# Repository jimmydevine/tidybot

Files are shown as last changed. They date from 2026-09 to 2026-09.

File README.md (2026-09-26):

# TidyBot

A modular cleaning robot for hard floors, heavy dog hair and automatic operation
across two floors. The project is intended to become open source and adaptable to
different homes and component inventories.

| Section | Purpose |
|---|---|
| Middle electronics core | Shared battery, power distribution, central computing and structural frame |
| Bottom working unit | Wheeled vacuum/mop, or airborne duster with passive feet; resident sofa extension fits the vacuum |
| Top unit | Cap/display or a lift assembly carrying the core and attached bottom |

The completed system must clean, exchange tool modules and swap battery
cartridges automatically. Stations keep spare packs charged while the robot works.
Stations use removable bulk water and waste containers; periodic manual servicing
is accepted. Vacuuming comes first, then mopping and higher-area cleaning.

## Current work: whole-system design

**Bottom-frame comparison:** [T was rejected](docs/BOTTOM_CHASSIS.md).
Keeping the separate motor supports while integrating the surrounding frame adds
about **55 g** and obstructs head withdrawal. The [interactive review](design/system/output/bottom_chassis.html)
shows the material and conflicts. No new mass increase is adopted. The whole old
support/caster scope is only 681 g against a 775 g vacuum deficit, so chassis
changes alone cannot meet the limit. Next compare a chassis carrying the motor
brackets directly, plus lighter power-converter and bin/air-path construction.

**Core support comparison:** [S combines equipment supports and the fixed battery
receiver](docs/CORE_SUPPORT.md), with an [interactive cartridge-path view](design/system/output/core_support.html).
The replacement is about 154 g versus the former 210 g local allocation, a
conditional saving of about 56 g. Battery cells, the complete cartridge, sensors,
protection and module locks remain. This alone projects a 5.219 kg vacuum transfer
assembly, still about 719 g above the limit; no saving is booked yet. T above
evaluates the separately budgeted bottom frame and drive/power supports.

**Integrated head frame:** [R combines the end walls, pivot seats, skids and
pitch-stop supports](docs/INTEGRATED_HEAD.md), with [geometry views](design/system/output/integrated_head.svg)
and a [part-by-part mass comparison](design/system/output/integrated_head.md).
The candidate is about 162 g against the existing 170 g frame/compliance scope:
only about 8 g conditional saving. Powered lift remains. The withdrawal check
also corrects carrier-support interference with the wheel envelopes. Larger
shared assemblies still need redesign to close the weight deficit; no new saving
is booked and these are review models, not fabrication files.

**Owner mass budgets:** [4.5 kg maximum for transfer flights and 3.5 kg target
for sustained hovering](docs/MASS_BUDGETS.md), including core, battery and
loaded working module, excluding the lift top. The
[current budget check](design/system/output/mass_budgets.md) identifies the
remaining reductions; an estimate above its budget remains a redesign candidate.

**Sofa attachment direction:** keep [one dock-swapped extension on each floor](docs/SOFA_ATTACHMENT.md).
It replaces the ordinary powered head while sharing the vacuum drivetrain,
bin, filter and blower. Park the extension and reinstall the normal head before
flight. The [layout comparison](design/system/output/sofa_attachment.html)
reserves a 615 mm stowed depth; the owner confirmed approximate sofa approach
and turning space. Receiver placement now clears sampled head motion; complete
automatic head exchange remains to resolve. Including its proposed interface, the ordinary transfer assembly
is 5.275 kg at maximum modeled debris, still **775 g above the 4.5 kg budget**.

**Head coupling detail:** [P carrier and supported exchange](docs/HEAD_COUPLING.md)
adds local FreeCAD/STEP assemblies, a documented contact reference and an
[interactive withdrawal view](design/system/output/head_coupling.html).
The revised interface needs 120 mm withdrawal and 735 mm station handling
depth before margins. Carrier scope is about 68 g against an allocation of
70 g drawn from existing allowances; complete head compliance, latch guides
and service supports remain unfinished. The complete transfer estimate above
is unchanged. This candidate does not release print files or purchases.

**Weight correction:** the [mass audit and revised work direction](docs/MASS_OPTIMIZATION_REVIEW.md)
take priority over extending the K/M mechanisms. Their rising totals combine
heavy separate wheel supports with additional, partly overlapping allowances.
Next compare a simpler integrated chassis and vacuum-head support, reconcile
one mass entry per physical part, and retain cleaning/automation requirements.
The studies below remain comparison candidates; no weight savings are yet booked.

**Q passive-head comparison:** [independent slides with low head pivots](docs/PASSIVE_HEAD.md)
provide the required sampled travel/tilt, but require redesigned cassette end
frames. The [interactive model](design/system/output/passive_head.html) shows
the motion. A separate dock-only mechanism offers only 22–25 g conditional
saving and has unresolved friction/release behavior. Keep the lift allowance;
integrate the guides into the existing head frame before adding hardware.

**N simplification comparison:** [fixed motor supports and a common crossmember](docs/FIXED_DRIVE_COMPARISON.md)
offer a conditional **230 g reduction**, with all other M allowances retained.
The [interactive review](design/system/output/fixed_drive.html) shows the cost:
greater head travel/tilt and an unresolved wet-threshold load split in the mop.
Complete those checks before adopting the candidate or changing the main mass
ledger. Nominal geometry and a complete local mass scope are available for review.

**M floating-head integration:** the [motion and load study](docs/FLOATING_HEAD_DESIGN.md)
adds separate moving-head mass and proposes clearance for working/raised heads.
The [interactive views](design/system/output/floating_heads.html) show the revised
vacuum power shelf, mop tank and shared electronics positions. Sampled height
stays below 180 mm; added mount/lift allowances bring the vacuum/mop planning
cases to **5.32 / 4.95 kg**. Tightened roller/drive envelopes and actual guide/lift
hardware still need detailed fit checks. No new print or purchase is released.

**L spring and ride-height study:** the [updated suspension calculation](docs/SUSPENSION_SPRING_SELECTION.md)
separates moving pod weight from spring-supported load and checks empty/full
containers, tool pressure and caster direction. The
[interactive results](design/system/output/suspension_springs.html) show fixed
settings for each module and a 10.7 mm stock spring candidate. Nominal spring
checks pass, while some tolerance cases fail. Complete spring selection and
floating-head integration before fabrication; K carried-mass estimates remain.

**K connected drivetrain candidate:** the [pod joints and captured stops](docs/POD_JOINTS_AND_STOPS.md)
add a metal tray, bearing blocks and bolted frame connections. The
[interactive review](design/system/output/pod_joints.html) shows the closed stop
slot. Including the detailed pod hardware raises current ground mass planning
to about **5.14 kg vacuum, 4.86 kg mop and 5.42 kg sofa vacuum**. Spring selection,
remaining joint qualification and fabrication details remain open. L supersedes
K's preload-range inference; G/J are preserved for comparison.

**J wheel-pod mechanism candidate:** the [moving cradle and spring design](docs/WHEEL_POD_MECHANISM.md)
adds a catalog motor bracket, an 8 mm pivot with internal retainers, and rocking
spring seats. Review the [interactive mechanism](design/system/output/wheel_pod.html).
The detailed pin load screen passes, but complete joints, stops and spring
selection remain open. The sofa module is already at the preload limit; the
installed mass must be reconciled before selecting springs or claiming savings.

**I height/mounting candidate:** the [revised layout](docs/HEIGHT_AND_CASTER_LAYOUT.md)
uses a C1 lidar and rotated lift-connector reservation to retain the proposed
wheel travel at a sampled 177.35 mm height, or 179.35 mm with a 2 mm reserve.
A documented caster fitting now has space for its full threaded stem; nearby
equipment moves upward while meeting the existing bin/tank volume targets.
Start with the [interactive comparison](design/system/output/height_mounting.html).
Caster retention and detailed suspension joints remain open; G is still the
complete mass baseline.

**H suspension/support study:** [wheel pivots and caster support](docs/FLOOR_SUPPORT_DESIGN.md)
adds mechanism CAD, impact/spring calculations and an
[interactive travel view](design/system/output/floor_support.html). The proposed
downward wheel travel exposes a height conflict: the nominal 179.1 mm pose can
reach about 181.9 mm in the support model. Frame joints and caster fitting remain
open; G's complete mass estimates remain unchanged.

**Revision G frame candidate:** the [dimensioned corner/frame design](docs/FRAME_JOINT_DESIGN.md)
adds a metal load path through the module joints and checks it against the existing
600 N factored requirement. It adds about 14 g to the F estimate and brings
modeled ground height to 179.1 mm. The floor bridge route is cleared, while its
unfinished replacement supports remain fully counted. Start with the
[core frame CAD](design/system/output/frame_joints_core.FCStd) or
[joint drawing](design/system/output/frame_joints.svg).

**Revision F power-partition candidate:** the [new layout and mass comparison](docs/CORE_POWER_PARTITION.md)
moves floor-specific converters out of the shared core. It saves an estimated
246 g on the airborne duster and 103 g on the mop; vacuum/sofa assemblies gain
87 g with the added support/interface allowances. See the
[F viewer](design/system/output/core_partition.html) for the proposed layout.
The C/E viewers below retain the earlier layout and mass for comparison.

The [weight optimization review](docs/MASS_OPTIMIZATION_REVIEW.md) identifies
unfinished mass allowances and redesign priorities across every module. Current
weights are feasibility estimates; they are not the minimum achievable design.

**Revision E airborne supplement:** the preferred elevated duster omits its
drivetrain, suction system and sofa telescope. See the
[interactive airborne comparison](design/system/output/airborne_dusting.html) and
[dusting design](docs/AIRBORNE_DUSTING.md) for its 481 g nominal tool bottom,
rear-boom balance, documented EDF mass/power comparisons, automatic station
handling and complete flight-energy budgets.
The earlier wheeled duster below remains comparison evidence. Vacuum, mop and
under-sofa modules retain their drive.

**2026-09-13, revision C review: design every module before selecting battery cells.** The active
[whole-system design](docs/SYSTEM_DESIGN.md) covers the electronics/sensor core,
vacuum/drive, mop/drive, under-sofa vacuum, duster, whole-assembly lift and automatic
stations. It supersedes the earlier instruction to defer lift sizing and the
battery-first preference. Existing motor/controller, brush/filter and blower
orders remain recorded; this study adds no purchases.

Start with the [interactive layout and budget viewer](design/system/output/system_design.html).
It compares complete assemblies, batteries, payload and assumed guard loss, with
stowed/extended views and individual component inspection. The
[generated report](design/system/output/system_budget.md),
[robot hardware CSV](design/system/output/system_hardware.csv),
[station hardware CSV](design/system/output/station_hardware.csv) and
[FreeCAD/STEP layouts](design/system/README.md) make the design reviewable.
Inputs are in [system_design.json](config/system_design.json).

[Automatic battery exchange](docs/BATTERY_EXCHANGE.md) now uses a cartridge,
station logic power during handling, and two spare packs in four bays per floor.
Five packs serve the two-floor system, with one carried. Capacity and current
capability remain open; extra packs do not establish unlimited cleaning or flight.

[Lift footprint review](docs/LIFT_LAYOUT_REVIEW.md) explains why the earlier
rotor layout became long. The owner considers its 644 × 1444 mm size excessive;
compact lift and duster geometry are now under review. The updated dusting target
is ceiling fans about 7 ft high, 1 ft below the ceiling, with about 2 ft tool reach.
Baseline duster CAD retains the previous horizontal mechanism; the airborne
supplement provides the rear angled-boom reference for fan-edge access. The longer under-sofa telescope remains required.
The review now includes [weight priorities and ducted-fan comparisons](docs/LIFT_LAYOUT_REVIEW.md#weight-reduction-and-ducted-fan-comparison):
compare complete guarded-propeller, hover-duct and compact EDF installations
before selecting a smaller lift layout or revising the mass allowances.

The everyday floor configurations use a **275 × 275 × 180 mm** nominal allocation
and 270 mm main print panels. The [suspension travel envelope](docs/FLOOR_SUPPORT_DESIGN.md)
still needs qualification. G's earlier estimated loaded floor mass is **4.49–5.06 kg**;
the K drivetrain scenario above increases it to about **4.86–5.42 kg**. Earlier
modeled normal power is **58–122 W**. These are engineering estimates, not
measurements. The eight-rotor lift candidate is much larger: approximately
644 × 1444 mm, about 8.2–8.5 kg complete nominal mass and over 2 kW estimated hover
power. Several upper mass cases fail the thrust-margin screen. Battery current
delivery, flight qualification, custom locks/power hardware, telescope mechanics
and detailed fabrication remain open.

The owner updates and unresolved design gates are retained in the
[design document](docs/SYSTEM_DESIGN.md#13-fabrication-verification-and-remaining-work).
Earlier studies below remain evidence and implementation history; the whole-system
record controls current layout, carried mass and battery decisions.

## Earlier component and ground studies

| Earlier record | Contents |
|---|---|
| [Selected-component integration viewer](design/ground/output/vacuum_integration.html) | Rotatable current placement, layer controls, dimensions and service views; not printable geometry |
| [Integration decisions](docs/VACUUM_INTEGRATION.md) | Trailing wheel pods, interchangeable head, rear bin/filter/blower arrangement and unresolved fit |
| [Converter and caster packaging](docs/VACUUM_POWER_PACKAGING.md) | Distributor converter baseline, cooling stack, corrected swivel allowance and docking clearance |
| [Power and remaining hardware](docs/VACUUM_POWER_AND_HARDWARE.md) | Functional diagram, load allocations and consolidated procurement worksheet with open selections |
| [Ground component recommendation](docs/GROUND_COMPONENT_RECOMMENDATION.md) | Proposed geared drive, 72 mm compliant wheels, wet-floor layout and cleaning-component selection; prices and remaining integration work |
| [Drivetrain sourcing](docs/DRIVETRAIN_SOURCING.md) | Exact distributor part numbers and prices; stock versus Marketplace/on-demand fulfillment; conditional motor and controller alternatives |
| [Current vacuum build plan](docs/VACUUM_MODULE_NEXT_PASS.md) | Orders, work during delivery, arrival checks, first assembly and cleaning milestones; retained earlier layout study |
| [Vacuum recommendation review](docs/VACUUM_RECOMMENDATION_REVIEW.md) | Hair-priority brush investigation, cutting versus shedding, washable-filter candidate, sourcing and evidence limits |
| [Cassette and brush comparison plan](docs/VACUUM_CASSETTE_PLAN.md) | Two levels of replacement, first comparison samples, receiver/air/electrical interface, build order and pickup trials |
| [Earlier vacuum component selection](docs/VACUUM_COMPONENT_SELECTION.md) | Superseded consumable choice; retained blower sources, curve discrepancies, airflow and power calculations |
| [Ground module design](docs/GROUND_MODULE_DESIGN.md) | Core, vacuum, cap, automatic joints and next physical milestones |
| [Low-clearance bottom](docs/LOW_CLEARANCE_HEAD.md) | Separate interchangeable bottom; 50 mm clearance, 36-inch depth and front-only access |
| [Owned-parts reuse](docs/OWNED_PARTS_REUSE.md) | Pi 4, A1 LiDAR, 60 mm wheel reference, two 18 RPM encoder motors and CBM blower; missing electronics |
| [Drive motor alternatives](docs/DRIVE_MOTOR_OPTIONS.md) | Faster encoder gearmotors for 90/60 mm wheels; prices, torque limits, mounts and control requirements |
| [Rolling drive rig](design/experiments/drive_rig/README.md) | Optional BDUAV experiment, paused as the robot's development path; fit history and recording tools retained |
| [Rig preparation before controller delivery](design/experiments/drive_rig/PREPARATION.md) | Two ST boards purchased; remaining supplies, fit checks, measurement worksheet and USB-only diagnostics |
| [Vacuum head and consumables](docs/VACUUM_HEAD.md) | Owned roller/brush/filter kit, proposed cassette and remaining fit measurements |
| [Dimensioned head layout](design/ground/output/vacuum_head_layout.html) | Compare both roller lengths; measured envelopes and proposed cassette clearances |
| [Earlier inventory-based placement](design/ground/output/ground_layout.html) | Core, complete vacuum bottom and cap; dimensioned views and service paths |
| [Earlier placement decisions](docs/GROUND_PLACEMENT.md) | Proposed 275 × 275 × 178 mm body, side-access core trays, rear bin, joint zones and station separation |
| [Inventory record](config/owned_parts.json) | Owned variants, quantities where known, missing items and resolved questions |
| [Ground component ledger](config/ground_components.csv) | Per-assembly requirements, candidates and measured mass fields; not an order |
| [Assembly mass record](config/ground_assemblies.csv) | Complete sections with empty/loaded states kept separate |
| [Design proposal](docs/DESIGN_RESET.md) | Confirmed requirements and overall architecture |
| [Autonomy proposal](docs/AUTONOMY.md) | Scanning, local control, optional MCP/LLM planning and portable profiles |
| [Example home profile](config/examples/straight_stair_home.json) | Owner measurements and explicit unknowns; design data only |
| [Design files](design/README.md) | Current records and retained earlier modeling tools |

Use TAZ 6-printed parts and purchased hardware, with machining kept within the
owner's available tools. A consolidated compatible parts list with costs will
accompany the component layout before proposing purchases. Robot parts and
automatic interfaces are not yet released for fabrication; control/MCP software
has not been implemented.

## Deferred studies

The [earlier packaging study](docs/PACKAGING_STUDY.md),
[interactive concept](design/output/concept.html),
[concept findings](docs/CONCEPT_FINDINGS.md) and
[propulsion comparison](docs/PROPULSION_COMPARISON.md) are retained references.
Their dimensions, flight-driven battery choice and mass estimates do not constrain
the new ground layout. The [EDF experiment](docs/EDF_BENCH_PLAN.md),
[shopping proposal](design/experiments/edf_bench/HARDWARE_LIST.md) and
[cradle files](design/experiments/edf_bench/README.md) are also deferred. The owned
fan remains mounted in the fitting v2 cradle; no thrust measurements were taken.

## Archive

Earlier CAD experiments and superseded architecture are preserved in
[archive/](archive/README.md). They do not govern the current design.

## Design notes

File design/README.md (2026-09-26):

# Design files

The active design is now the [whole-system study](system/README.md), covering all
bottoms, the electronics core, lift and automatic stations. Open the
[interactive review](system/output/system_design.html) or
[design decisions](../docs/SYSTEM_DESIGN.md). It supersedes the earlier lift
deferral and battery-first recommendation. The layouts below remain earlier
studies; their dimensions and mass assumptions do not override the system model.

**Earlier phase: [core and ground modules](../docs/GROUND_MODULE_DESIGN.md).**
Use the [recorded vacuum component selection](../config/vacuum_selection.json) for the
everyday vacuum and [owned_parts.json](../config/owned_parts.json) for inventory.
Track assembly requirements in [ground_components.csv](../config/ground_components.csv) and actual
module weighings in [ground_assemblies.csv](../config/ground_assemblies.csv).
The owner confirmed a low head for 50 mm sofa clearance, suggested a separate
module, and reported 36-inch depth with front-only access. The working design is
[a dedicated low-clearance bottom](../docs/LOW_CLEARANCE_HEAD.md). Its mechanism
is separate from the first core/cap/everyday-vacuum layout.

## Earlier selected-component integration

Open the [offline rotatable viewer](ground/output/vacuum_integration.html),
[FreeCAD model](ground/output/vacuum_integration.FCStd) or
[STEP model](ground/output/vacuum_integration.step). This pass uses the selected
Pololu drivetrain, TriCut reference, new filter allocation and BIQU blower.
It includes trailing wheel-pod motion reservations and conditional service paths.
The [design decisions](../docs/VACUUM_INTEGRATION.md),
[generated check report](ground/output/vacuum_integration_report.md) and
[power/hardware record](../docs/VACUUM_POWER_AND_HARDWARE.md) identify remaining work.
These are component references and wire reservations, not printable parts.

```sh
python3 design/ground/integrate_vacuum.py
python3 -m unittest discover -s design/ground -p 'test_*.py' -v
freecadcmd design/ground/export_integration.py
```

Inputs: [vacuum_integration.json](../config/vacuum_integration.json).
The generator uses standard Python; the CAD export requires FreeCAD.
The standalone viewer needs no web service or downloaded JavaScript library.
The [hardware worksheet](../config/vacuum_build_hardware.csv) is a procurement
breakdown, not an additional mass ledger or a complete approved purchase list.

## Earlier inventory-based ground placement

The owner has also requested a [rolling BDUAV drive rig](experiments/drive_rig/README.md).
Its [offline layout](experiments/drive_rig/output/drive_rig.html), printable fit parts,
complete hardware allowance and CSV measurement tools are separate from the full
robot placement. Motor firmware and physical qualification remain outstanding.
This ground test does not resume EDF or lift work.

Open the [offline assembly placement](ground/output/ground_layout.html) for the
core, vacuum bottom, cap and service paths. The body proposal is 275 × 275 mm,
178 mm high including the A1 reference, within the owner's 180 mm limit. Flexible
bristles may extend; main panels target whole 270 × 270 mm prints. Component sizes, sources and modeled
clearance checks are in the [coordinate report](ground/output/ground_report.md);
read the [placement decisions](../docs/GROUND_PLACEMENT.md) for assumptions.

```sh
python3 design/ground/generate.py
python3 design/ground/place_modules.py
python3 -m unittest discover -s design/ground -p 'test_*.py' -v
freecadcmd design/ground/export_placement.py
```

The placement command uses [ground_layout.json](../config/ground_layout.json), the
inventory and existing head study. It generates HTML, five SVG drawings, a JSON
snapshot and a report. FreeCAD separately exports the
[STEP](ground/output/ground_placement.step) and
[FreeCAD](ground/output/ground_placement.FCStd) inspection models. Wire outlines
reserve space; reference solids show component envelopes. No fabrication STL or
flight capability is supplied. Re-export CAD after changing placement inputs.

## Earlier inventory roller clearance study

Open the [offline ground-head comparison](ground/output/vacuum_head_layout.html)
for dimensioned top and side views of both owned roller lengths. It uses the
reported 28 mm roller diameters and shows the filter separately. Grey housing
and amber drive spaces are proposed allowances, with no motor, transmission or
end-fitting geometry released. See the [calculation report](ground/output/report.md)
and [vacuum-head notes](../docs/VACUUM_HEAD.md).

Regenerate from inventory and [allowance inputs](../config/vacuum_head_layout.json):

```sh
python3 design/ground/generate.py
```

This produces HTML, two standalone SVG drawings, a JSON snapshot and the report.
It imports no archived CAD or flight model. No STL is issued from a clearance study.

**The model and commands below reproduce the earlier, deferred concept.** Its
200 × 280 × 190 mm floor robot, 6S battery and estimated flight mass are not the
current ground-build specification. All propulsion selection and testing are on
hold until the other modules' dimensions and carried masses are established.

## Earlier concept model and feasibility screens

Open [the offline viewer](output/concept.html) in a browser. It compares four
configurations, shows the component layout and three station working states, and
lists the checks and purchase allowances. It makes no network requests; source
links open manufacturer pages only when selected.

Read the [generated numerical report](output/report.md) and the
[engineering findings](../docs/CONCEPT_FINDINGS.md) alongside the pictures. These are
bounding models, not printable parts or a validated flight design.

The separate [EDF bench draft](experiments/edf_bench/README.md) provides a force
lever layout and a **retaining-cradle correction**. The local housing gauge fit,
but the full v1 cradle interfered with a raised ring. V2 includes the measured ring
and a clearance groove; the owner confirms body/ring fit opposite the cables.
The bench uses that side underneath with cables upward. The owner has installed
the fan with M3 nuts and bolts. Further stand work and the
[purchasing proposal](experiments/edf_bench/HARDWARE_LIST.md) are deferred because
of cost. The [published-data propulsion comparison](../docs/PROPULSION_COMPARISON.md)
is also deferred under the owner's ground-first work order. The bench's
inputs and exports are independent of the robot envelope model below.

## Inputs and generation

| File | Role |
|---|---|
| [concept.json](../config/concept.json) | Body/rotor/station dimensions, candidate propulsion curves and explicit screening assumptions |
| [components.csv](../config/components.csv) | Per-section component mass, power, cost basis and inventory substitution notes |
| [Example home](../config/examples/straight_stair_home.json) | Approximate owner measurements in metres and unmeasured geometry left null |
| [study.py](study.py) | Component positions, geometry checks, mass/energy calculation and report generation |
| [generate.py](generate.py) | Scene construction and offline viewer generation |
| [viewer.html](viewer.html) | Viewer template; open the generated version rather than this template |

From the repository root, using standard Python (no packages to install):

```sh
python3 design/generate.py
python3 -m unittest discover -s design/tests -v
```

The generated JSON, report and HTML are retained as reviewable outputs. Edit inputs
or source, then regenerate; do not hand-edit output files. Component placements in
`study.py` need checking again whenever their envelopes change.

## CAD exports

After generating the study, run the FreeCAD headless executable from the repository
root (set `TIDYBOT_PROJECT_ROOT` if running from elsewhere):

```sh
freecadcmd design/export_freecad.py
```

| Model | STEP | FreeCAD |
|---|---|---|
| Default robot and component envelopes | [STEP](output/robot_concept.step) | [FreeCAD](output/robot_concept.FCStd) |
| Robot on an interior stair tread | [STEP](output/stair_concept.step) | [FreeCAD](output/stair_concept.FCStd) |
| Station with supported core and bottom exchange volumes | [STEP](output/station_concept.step) | [FreeCAD](output/station_concept.FCStd) |

FreeCAD 1.1.3 was used for the first exports. Wire outlines represent overall module
and guard envelopes. Cylinders represent rotor swept space and motor allowances;
boxes represent purchased components with packaging allowances. None of these shapes
specifies a blade, protective cage, chassis wall, latch or machined bracket to make.
The retained `.FCStd` files contain named features for inspection; source dimensions
and generation scripts remain authoritative.

The STEP/FreeCAD files contain the default configuration only. Other variants are
available in the viewer; change `default_variant` and regenerate both outputs to
export another configuration. No archived CAD library is imported.

## Scope of the checks

- Coordinates are x forward/upstairs, y left and z up, in millimetres. The current
  tread is centered on x=0 with contact height z=0.
- The guard is a conservative occupied cylinder, not a designed access barrier.
  Arms and motor envelopes are included in the sampled stair test. The simple
  in-body vertical supports are drawn but are not separately collision-tested.
- Contact checks use level wheels with yaw/position error. Lift assembly checks
  sample yaw, pitch and roll at their assumed negative, zero and positive bounds.
  Intermediate angles and a complete timed trajectory are not proven clear.
- The combined rail projection is a conservative width gate. The rails' thicknesses,
  exact cross-sections and terminal geometry remain unknown. There is no fabricated
  headroom, landing, doorway, bookcase pose or pet-free route.
- The visual station states establish working-volume locations. Interlocks,
  mechanisms, cable/hose routing, approach trajectories and recovery are not yet
  designed or tested.
- Component-box intersection checks do not establish mounting, cooling, usable bin
  volume, air sealing, structural strength or sensor visibility.
- Larger variants substitute motor mass only. Their larger arms, guards and
  propellers need their own estimates before a final mass/cost comparison.
- Power interpolation stays within the published test points. Low-voltage thrust
  and guard-loss factors are sensitivity assumptions; continuous ratings and
  installed performance must come from the selected hardware and tests.

`PASS_MODEL` and `PASS_ASSUMPTION` are local results. Every configuration remains
`NOT_VALIDATED` overall while required geometry and physical checks are unresolved.

## Verification of this study

The initial generated study was checked with 16 passing Python unit tests covering
geometry, mass accounting, propulsion interpolation and unresolved validation gates.
A local Chromium smoke test exercised all 24 combinations of configuration, top mode
and station state; the generated JavaScript also passed a syntax check. All three
FreeCAD documents reopened successfully, and their STEP exports contained valid,
nonempty shapes. Markdown links and Git whitespace checks passed.

These checks verify the calculation and review artifacts within their stated scope.
No physical pickup, thrust, thermal, structural or autonomous-operation test has
been performed.

The current [converter/caster packaging update](../docs/VACUUM_POWER_PACKAGING.md)
adds a nominal Cincon cooling stack and full caster swivel reference to the
integration viewer and CAD. The updated station clearance includes the core bay
projecting below the mating plane. These remain design reservations.

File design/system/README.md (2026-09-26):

# Whole-system engineering model

The [T bottom-chassis comparison](../../docs/BOTTOM_CHASSIS.md) is explicitly
rejected: the integrated surrounding frame is heavier and obstructs head
movement/withdrawal. Run `export_bottom_chassis_freecad.py` under FreeCAD, then
`bottom_chassis.py` and `bottom_chassis_viewer.py`. The [review](output/bottom_chassis.html)
and [ledger](output/bottom_chassis.md) preserve failed geometry and complete mass
ownership. Tests passing means the comparison is reproducible, not that the
frame passes its design requirements. Refresh P/Q/R/S/T exports after source changes.

The [S core-support study](../../docs/CORE_SUPPORT.md) audits the common core and
replaces only `core_prints` + `battery_receiver` with a material-based candidate.
Run `core_support.py`, `export_core_support_freecad.py` under FreeCAD, then
`core_support_viewer.py`. Review [the report](output/core_support.md),
[interactive exchange view](output/core_support.html), and installed/withdrawn
`core_support_*.FCStd` / `.step` models. CAD checks include protected cartridge
reservations and new-part removal paths on vacuum/mop. The duster comparison is
mass only. Refresh P/Q/R/S CAD fingerprints after model-source changes before
running the full tests.

The [R integrated head frame](../../docs/INTEGRATED_HEAD.md) replaces the gross
head box with end walls, bearing seats, skid ramps, pitch-stop slots and a hood.
Its [report](output/integrated_head.md) reconciles the complete 170 g local scope
and calculates air-connector motion. Review the [drawing](output/integrated_head.svg)
and `integrated_head_*.FCStd` / `.step` assemblies. Run
`freecadcmd design/system/export_integrated_head_freecad.py`, then
`python3 design/system/integrated_head.py` from the repository root. After source
changes refresh P and Q CAD as well before the full test suite. R corrects the P
carrier riser/shoe placement and includes the N wheel envelopes in withdrawal
checks. No new weight saving or fabrication release is booked.

The [Q passive-head comparison](../../docs/PASSIVE_HEAD.md) evaluates twin-slide
kinematics, low pivots, force sensitivity and complete local mass scope. Run
`passive_head.py`, `passive_head_viewer.py` and `export_passive_head_freecad.py`
(under FreeCAD). Its [viewer](output/passive_head.html) and
[report](output/passive_head.md) retain the failed friction cases and necessary
head-frame rework. The powered-lift allowance remains until its functions are
covered; no weight reduction is booked. Refresh P's CAD fingerprint too after
model source changes before running the full tests.

Owner requirements are in `config/mass_budgets.json`: 4.5 kg transfer maximum
and 3.5 kg hover target for complete loaded non-lift assemblies. Run
`python3 design/system/mass_budgets.py` for the
[comparison](output/mass_budgets.md) and CSV/JSON outputs. Cap removal, maximum
contents, hardware uncertainty and unfinished candidate status are explicit.
See [budget definitions](../../docs/MASS_BUDGETS.md); these limits do not change
historical component masses or establish sufficient propulsion.

The [P removable head coupling](../../docs/HEAD_COUPLING.md) details a fixed
carrier, captured guides, spring-engaged keys, air face and protected electrical
interface. Run `head_coupling.py`, `head_coupling_viewer.py`, then
`export_head_coupling_freecad.py` under FreeCAD. Review the
[withdrawal illustration](output/head_coupling.html), [report](output/head_coupling.md)
and [CAD check scope](output/head_coupling_cad_checks.json). The latter includes
a model-source fingerprint; regenerate after source changes. P's 120 mm stroke
supersedes O's provisional 100 mm for this interface; whole assembly mass is
unchanged. Compliance, latch housings and service supports are not complete.

The [O sofa-attachment comparison](../../docs/SOFA_ATTACHMENT.md) leaves one
extension at each floor station and uses the normal vacuum for transfer flights.
Run `sofa_attachment.py` for the [interactive layout](output/sofa_attachment.html),
SVGs, mass CSV and [calculation report](output/sofa_attachment.md), then refresh
`mass_budgets.py`. The new head interface adds an explicit candidate allowance;
the existing manual cassette is not an automatic exchange mechanism. These are
space reservations, with room clearance, complete joints and cleaning/traction
unresolved; the previous dedicated sofa bottom remains a comparison.

The [weight correction](../../docs/MASS_OPTIMIZATION_REVIEW.md) is the current
priority. Run `mass_growth_audit.py` for the [G–M reconciliation](output/mass_growth_audit.md)
and complete row ledger. K/M remain comparison candidates while simpler chassis
and head support arrangements are evaluated; the audit changes no mass values.

The [N fixed-drive comparison](../../docs/FIXED_DRIVE_COMPARISON.md) provides
nominal CAD and an itemized replacement scope with a conditional 230 g saving.
Run `fixed_drive.py` for its [report](output/fixed_drive.md) and
[interactive view](output/fixed_drive.html), then
`export_fixed_drive_freecad.py` for CAD. Head motion, mop weight distribution
and complete joints remain gates before adoption; no STLs are released.

The [M floating-head integration](../../docs/FLOATING_HEAD_DESIGN.md) proposes
working/raised clearance and solves head force with wheel equilibrium. Use the
[viewer](output/floating_heads.html), [report](output/floating_heads.md), or
`floating_heads_{vacuum,mop}_{working,raised}.FCStd` / `.step` exports. Generate
with `floating_heads.py`, then `export_floating_heads_freecad.py` using FreeCAD.
These are motion allocations, not finished guides or printable mounts. Added
hardware allowances give 5.32 kg vacuum and 4.95 kg mop planning cases; shared
core changes still require integration with sofa/duster. L wheel-spring
tolerance failures remain open.

The [L spring/ride-height study](../../docs/SUSPENSION_SPRING_SELECTION.md) corrects
spring loading for moving wheel/pod mass, compares catalog springs and solves
empty/full contents and tool-contact cases. Run `suspension_springs.py` for the
[interactive results](output/suspension_springs.html) and
[report](output/suspension_springs.md), then `export_suspension_springs_freecad.py`
with FreeCAD for representative pod assemblies. K carried masses remain the
planning scenario. Spring tolerances, floating-head travel and dynamic threshold
crossing remain open; the catalog candidate is not a purchase release.

The [K connected pod/stop study](../../docs/POD_JOINTS_AND_STOPS.md) is the current
ground-drivetrain mass planning candidate. It replaces G's two pod allowances
with modeled metalwork, hardware and completion reserves, preserving other
frame/carrier allowances. Run `pod_joints.py`, `export_pod_joints_freecad.py` with
FreeCAD, then `pod_joints.py` again to import the CAD mass. Use the
[interactive stop view](output/pod_joints.html), [report](output/pod_joints.md) or
[FreeCAD](output/pod_joints.FCStd). Complete joint/fatigue qualification, spring
selection and fabrication release remain open. J exports are retained unchanged.

The [J wheel-pod mechanism](../../docs/WHEEL_POD_MECHANISM.md) adds a reconstructed
catalog motor bracket, relieved moving cradle, internal pivot-retainer stack and
rocking spring/guide geometry. `wheel_pod.py` generates the
[interactive mechanism](output/wheel_pod.html) and [report](output/wheel_pod.md)
from [J inputs](../../config/wheel_pod.json). Run
`freecadcmd design/system/export_wheel_pod_freecad.py` for nominal/bump/droop
candidate solids and a partial mass ledger. The design record explains the
optional supplier STEP inputs for exact wheel/hub mating checks. Complete
frame joints, stops, bearing fits and spring selection remain open; G mass is
unchanged. The nominal sofa preload slightly exceeds the adjustment range.

The [I height/mounting overlay](../../docs/HEIGHT_AND_CASTER_LAYOUT.md) proposes
a C1 lidar, rotates the lift-connector reservation and makes room for a documented
caster fitting. It passes the sampled 180 mm height screen including a 2 mm
reserve, with the same H wheel travel. `height_mounting.py` generates the
[comparison](output/height_mounting.html) and [report](output/height_mounting.md)
from [I inputs](../../config/height_mounting.json). Run
`freecadcmd design/system/export_height_mounting_freecad.py` for the three revised
ground layouts. Caster pull-out retention and detailed suspension joints remain
unqualified; complete G masses are retained separately from candidate deltas.

The [H suspension/support study](../../docs/FLOOR_SUPPORT_DESIGN.md) details pivot
and caster candidates without replacing G's complete mass ledger.
`floor_support.py` generates the [travel viewer](output/floor_support.html),
load calculations and stock ledger from [inputs](../../config/floor_support.json).
`export_floor_support_freecad.py` exports three bottom references and bump/droop
poses. Its height screen fails with the proposed droop, so the nominal G fit must
not be treated as a verified suspension envelope.

The [G frame/joint candidate](../../docs/FRAME_JOINT_DESIGN.md) uses dimensioned
stock-tube corners, edgewise rails, bearing pads and slider geometry. It adds
load/radius/capacity screens and clears a replacement floor-bridge route while
retaining the current carrier mass. `frame_joints.py` applies
[G inputs](../../config/frame_joints.json) to F; `export_frame_joints_freecad.py`
exports the full layouts and a core-only reference. The top seat changes to
124.1 mm. Start with [the generated report](output/frame_joints.md).

The [revision F power-partition candidate](../../docs/CORE_POWER_PARTITION.md)
adds a dimensioned bottom-owned power carrier, corrected upward removal path,
raw-pack interface contract and full configuration mass comparisons.
`core_partition.py` applies [F inputs](../../config/core_partition.json) to the
unchanged C/E sources. Its [viewer](output/core_partition.html),
[report](output/core_partition.md) and `core_partition*.FCStd`/`.step` exports
are the current partition proposal; the original outputs below remain baseline
comparisons. Run `python3 design/system/core_partition.py` and
`freecadcmd design/system/export_core_partition_freecad.py` to regenerate F.

This is the active cross-module design study. It supersedes the earlier work order
that deferred lift and the battery-first recommendation. Hardware need not arrive
to refine this model. It is a preliminary engineering design, not a fabrication
release or a demonstration of autonomous flight.

The current [airborne supplement](../../docs/AIRBORNE_DUSTING.md) replaces the
old wheeled elevated duster with a passive-foot tool bottom. Revision E moves the
boom rearward, refines camera mass placement and compares two documented EDF
assemblies with the complete carried vacuum, mop, sofa and duster loads. Use its
[interactive comparison](output/airborne_dusting.html),
[hardware and results](output/airborne_dusting.md), and
[FreeCAD](output/airborne_dusting.FCStd) / [STEP](output/airborne_dusting.step).
`airborne_study.py` imports the core/pack/lift baseline and applies
[airborne_dusting.json](../../config/airborne_dusting.json). Reproduce it with
`python3 design/system/airborne_study.py`, then
`freecadcmd design/system/export_airborne_freecad.py`.
The original wheeled duster exports below remain earlier comparison geometry.
The [airborne verification record](output/airborne_validation.md) separates the
new calculation/CAD checks from physical tests and the earlier baseline exports.

- [Editable inputs](../../config/system_design.json): geometry, hardware, mass intervals,
  loads, mechanisms, battery comparison inputs and propulsion reference curve.
- `build.py`: assembly accounting, geometry checks, CG/support, traction, airflow,
  flight and energy calculations; generates the review artifacts.
- `viewer.html`: self-contained interactive layout and budget viewer template.
- `export_freecad.py`: exports dimensioned component proxies and reserved spaces.
- `test_system.py`: independent calculation and assembly-accounting checks.
- [Interactive review](output/system_design.html): start here.
- [Lift footprint review](../../docs/LIFT_LAYOUT_REVIEW.md): current size drivers,
  compact-layout direction and the updated ceiling-fan dusting target.
- [Battery exchange](../../docs/BATTERY_EXCHANGE.md): automatic cartridges, station
  power handover, charged spares and charging-throughput assumptions.
- [Design document](../../docs/SYSTEM_DESIGN.md): decisions, hardware interfaces and remaining gaps.
- [Verification record](output/validation.md): model/browser/CAD checks and input fingerprints.

Ground CAD: [vacuum](output/vacuum.FCStd), [mop](output/mop.FCStd),
[sofa tool](output/low.FCStd), [duster](output/dust.FCStd).
Lift comparisons include the vacuum bottom: [quad](output/quad10.FCStd),
[hex](output/hex10.FCStd), [octo](output/octo10.FCStd).
Also available: [extended sofa tool](output/low_extended.FCStd),
[extended duster](output/dust_extended.FCStd), [station](output/station.FCStd).
Each has a same-named `.step` export. The viewer composes all bottom/top choices;
the three lift CAD files use the vacuum as their common comparison payload.

Reproduce with `python design/system/build.py`, then
`python -m unittest discover -s design/system -p 'test_*.py'`.
Run `freecadcmd design/system/export_freecad.py` for FreeCAD/STEP exports.

Mass intervals are engineering allowances, not statistical confidence intervals.
Catalog figures are not owner measurements. Source URLs and the basis of each row
travel with the hardware worksheet. A single assembled robot contains one core,
one bottom, one top and one battery; station spares are counted separately.

Revision B adds one cartridge tare and fixed exchange hardware to each robot,
plus a four-bay battery rack per station. The core subtotal includes cartridge
hardware; the bare cell pack is separate. Stored spares never enter carried mass.

Revision C is a requirements/layout review. Existing rotor and horizontal duster
geometry remains comparison evidence; neither the large lift footprint nor fan
cleaning is approved by the numerical checks. Regenerate the explanatory drawing
with `python3 design/system/draw_lift_layout_review.py` after building the model.

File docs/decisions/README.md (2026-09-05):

# Architecture Decision Records

One file per decision that would be expensive to reverse. The point is to preserve the
*reasoning*, so that in two years you can tell the difference between "we chose this
deliberately" and "it just ended up that way."

Format: `NNNN-short-title.md`, numbered in the order decided.

Status is one of: **Proposed** / **Accepted** / **Superseded by NNNN** / **Rejected**.

Never edit an Accepted ADR's decision. Write a new one that supersedes it.

## Template

```markdown
# NNNN. Title

**Status:** Proposed
**Date:** YYYY-MM-DD

## Context
What forces are at play? What makes this a real decision rather than an obvious one?

## Decision
What we are doing. Stated plainly, in the active voice.

## Consequences
What gets easier. What gets harder. What we are accepting as a cost.

## Alternatives considered
What else was on the table, and the specific reason it lost.
```

## Index

| # | Title | Status |
|---|---|---|
| [0001](0001-locomotion-in-base.md) | Locomotion lives in the base, not in floor modules | Accepted |
| [0002](0002-bus-voltage-24v.md) | 24 V nominal DC bus | Accepted |
| [0003](0003-can-bus.md) | CAN for the inter-module bus | Accepted |
| [0004](0004-two-ports-top-bottom.md) | Two ports (top and bottom); sensors use an accessory rail | Accepted |
| [0005](0005-print-constraints-taz6.md) | Design rules for the LulzBot TAZ 6 | Accepted |
| [0006](0006-tri-post-coupling.md) | Three tapered posts with cross pins | Accepted |
| [0007](0007-coaxial-ports-tension-path.md) | Coaxial ports; the base is a structural member | Accepted |

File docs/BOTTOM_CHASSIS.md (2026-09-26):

# Bottom chassis integration — T comparison

**Decision: reject this arrangement.** Combining the surrounding frame while
retaining N’s separate motor-support angles and crossmember does not reduce the
complete installed estimate. The new frame also obstructs parts of the head
motion and withdrawal path. These are reported failures, not an adopted design.

Review the [interactive frame and obstructions](../design/system/output/bottom_chassis.html),
[complete mass calculation](../design/system/output/bottom_chassis.md),
[itemized ledger](../design/system/output/bottom_chassis_mass.csv), and
[vacuum CAD](../design/system/output/bottom_chassis_vacuum.FCStd).
The [mop CAD](../design/system/output/bottom_chassis_mop.FCStd) uses the same frame
routes with its lower control/power shelves. Both have matching STEP exports.

| Complete local support scope | Previous estimate | T comparison | Increase |
|---|---:|---:|---:|
| Vacuum | 680.9 g | 735.7 g | 54.8 g |
| Mop | 676.9 g | 732.7 g | 55.7 g |

This scope includes the general bottom frame, complete N wheel supports,
complete F mechanical power carrier, M risers and caster installation. It
excludes the motors, wheels, hubs, cleaning hardware and electrical components,
which remain fully counted elsewhere. The old H route geometry had no separate
booked mass, so deleting it cannot produce a saving.

T replaces the old scopes with dimensioned material and explicit remaining
hardware. The caster plate has one owner. The newer I caster/stem/retention
allocation totals **142 g**, versus the old **112 g** installed-caster row;
this corrects 30 g of the increase before counting the new saddle. The fitting
and positive airborne retention remain unqualified. No measured weight is claimed.

T alone would give **5.330 kg vacuum / 4.760 kg mop**, at maximum modeled contents,
including core and battery and excluding the lift and removed cap. R and S
reductions are not stacked. Historical O/N comparison totals remain unchanged;
their old caster allowance is incomplete and those figures are not final masses.

There is a useful limit to the chassis work: the vacuum needs **774.8 g** removed,
while this entire old support/caster scope is only **680.9 g**. Even a physically
impossible zero-mass replacement would leave **4.594 kg**. Other assemblies must
also change to meet the 4.5 kg requirement.

The proposed side rails connect to N’s existing cleats and support the head
receiver and power shelves. A rear box beam routes below the rear cliff windows,
behind the bin, and carries the caster saddle. Four corner seats retain the
86 mm core mating datum. Component locations, purchased drivetrain parts,
cleaning capacities, head lift and automatic interfaces are preserved.

The CAD check found no internal material overlap. It does find obstructions
between the inner power web and head hardware, and between the front seats or
controller support and the departing carrier. Core removal is checked after
retracting the four lower core sliders; the S supports are included as a fit
comparison without taking their mass saving. Local bending screens do not
qualify frame torsion, joints, notches, buckling, shaft loads or flight retention.

Stop detailing this arrangement. The next comparisons are:

1. A structural tray carrying the existing motor brackets directly, replacing
   N’s separate support angles and crossmember as part of the chassis. Keep the
   wheel locations and 150 N wheel / 600 N module-interface load requirements.
2. A lighter implementation of the **190 g 24 V converter/cooling assembly**,
   retaining its required electrical output, thermal performance and protection.
3. Integrated bin/air-path construction, retaining 500 mL usable capacity,
   filtration, hair clearance and automatic emptying.

These are comparisons to develop, not permission to remove hardware allowances
or reduce performance. No printing or purchasing is needed for this rejected frame.

Reproduce from the repository root:

```sh
freecadcmd design/system/export_bottom_chassis_freecad.py
python3 design/system/bottom_chassis.py
python3 design/system/bottom_chassis_viewer.py
python3 -m unittest discover -s design/system -p 'test_*.py' -q
```

After changing model source, also regenerate P/Q/R/S CAD fingerprints before
running the full suite. Tests verify the accounting and that failed geometry
remains explicitly rejected; passing tests do not mean this frame is fit to build.

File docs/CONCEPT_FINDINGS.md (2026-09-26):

# First dimensioned concept: findings and next decision

**Historical concept — ground packaging superseded 2026-09-05.** Current work is
[core and ground modules](GROUND_MODULE_DESIGN.md). Propulsion selection and testing
are deferred until the other modules' dimensions and masses are established.
Numbers below are estimates for the earlier model; its floor envelope does not
fit the newly reported 50 mm sofa clearance.

2026-09-05. Open the [interactive concept](../design/output/concept.html),
[CAD exports](../design/README.md) and [generated checks](../design/output/report.md).
The model and ledger implement the first feasibility study promised in the roadmap
discussion. This is not a release of build-ready robot parts.

## What changed when we modeled the hardware

The trial core/bottom footprint is now **200 mm fore-aft × 280 mm wide**, with a
90 mm bottom, a 90 mm core and a 10 mm cap. The earlier 240 mm fore-aft sketch fails
the assumed tread landing error budget. The smaller body fits the modeled component
boxes, but packaging remains tight and has not yet included routed ducts and cables.

The strongest configuration in this first comparison uses four **9-inch propellers**
on a rectangular layout with motor centers at x=±245 mm and y=±145 mm. A rotor plane
300 mm above the contact surface produces an overall guard envelope of approximately
**749 × 549 × 315 mm**. It passes the currently implemented geometric screens. A low
200 mm rotor plane collides with the uphill step/arm envelope under the sampled errors.

The tested 12- and 15-inch layouts fail several screens. The particular 12-inch motor
reference also lacks enough thrust for the assembled mass. This rejects those tested
combinations, not every motor or layout using those propeller diameters.

## The mass and power result is marginal

The reference mass is **4.22 kg loaded**: core 1.66 kg, vacuum bottom including a
150 g debris allowance 1.33 kg, and lift top 1.24 kg. Estimated masses use ±30% and
manufacturer masses ±5% as sensitivity bounds, giving **3.34–5.10 kg**. These are
deliberate uncertainty scenarios, not statistical confidence intervals.

The small-prop reference is Hobbywing's XRotor/RTF 3110 900KV with HQ9x4x3 propellers.
Its manufacturer table is measured at **24 V** and includes a **36-second full-throttle
note for that propeller**. That duration is not a hover endurance rating. The study
interpolates its thrust/power data without extrapolation and applies an unmeasured
15% thrust-loss allowance for the guarded installation. See the
[manufacturer specification](https://www.hobbywing.com/en/uploads/file/20251117/7845436338d9dbe2f43a50c4bae18544.pdf).

Using an additional unvalidated square-voltage sensitivity at 21 V gives approximately
**2.05:1 available thrust/weight** against a provisional 2:1 target. Only **96 g** of
nominal mass headroom remains. At the upper mass sensitivity, the ratio falls to
**1.69:1**. The mass and propulsion budget therefore remains open despite the nominal
screen passing. Greater guard losses also remove the margin.

The bench-equivalent hover estimate is approximately **1.06 kW**, including shared
electronics. If that power held at 21 V, the battery branch would carry roughly
**51 A** in hover; transient demand can be much higher. This is not a validated
low-voltage power curve, wire rating or connector selection.

A reference 6S 5 Ah pack stores 111 Wh nominal. An assumed 60 seconds of flight costs
about 17.7 Wh in this calculation. With 80% usable battery energy and a 123 W ground
load allowance, approximately **35 minutes of ground cleaning** remain after that
flight allowance. This does not establish a safe reserve or coverage per charge;
recharge during jobs is already acceptable in the brief. Automatic per-cell charge
management and the charge connector remain design work.

## Components to compare with existing inventory

The [CSV ledger](../config/components.csv) includes sources, dimensions, masses,
power allowances and price basis. These are candidates to compare, not a purchase order.

| Component | Reference | Why it is useful now |
|---|---|---|
| Battery | Grepow 6S 5 Ah reference, 755 g | Establishes real package size and substantial carried battery mass |
| Wheel motors | Pololu 5727, 99:1 HP 24 V with encoders, 102 g each | A lighter alternative to 37 mm gearmotors; current listing indicated backorder |
| Blower | Wonsmart WS7040-24-V200, external controller | Small clean-air blower for a filtered intake bench experiment |
| Core compute | Raspberry Pi 5 with cooling/storage allowance | Candidate for floor navigation; flight perception compute load still needs profiling |
| Flight controller | Pixhawk 6C Mini, current Model A | Dedicated flight controller with an explicit regulated supply requirement |

The wheel motor's **continuous gearbox torque limit**, not extrapolated stall torque,
must guide drive loading. Its manufacturer lists a 4 kg·cm continuous limit for this
gearbox family. Confirm brush drag, traction, motor heating and wheel support load in
the floor rig. [Pololu family specifications](https://www.pololu.com/category/384/24v-high-power-hp-25d-mm-gearmotors)

The blower is a clean-air reference, placed **after the bin and filter**. The
manufacturer drawing specifies a working point above 12 m³/h at 3 kPa and below 2.5 A
at 24 V; this says nothing by itself about pickup through our roller, ducts and dirty
filter. Regulated operation over the battery range and an appropriate external motor
controller remain to select. [Wonsmart drawing](https://www.wonsmartmotor.com/uploads/WS7040-24-V2004.pdf)

## Station result

The provisional **1,200 × 1,000 × 1,200 mm** station contains the default static
working volumes: overhead lift-top parking, a cap shelf/shuttle, an elevated core,
three bottom positions and removable tank/waste envelopes. Front/rear entry bounds,
parked height, cap storage width and tool-to-core vertical separation are checked.

The displayed mechanism is a set of envelopes. It still needs an actual elevator,
indexer, retained core supports, actuated coupling and guided connectors. Stored
bottoms are conceptual copies, not designed mop/duster modules. External doorways,
arrival paths, complete swap trajectories and fault recovery remain unverified.

## What should happen next

Follow the [ground module design](GROUND_MODULE_DESIGN.md): package the core and
ordinary vacuum bottom with station-accessible joints, then build a
rolling vacuum and measure its components and complete modules. Develop the cap,
dedicated low-clearance bottom, mop, duster and automatic service interfaces
against that evidence. Sofa access is resolved as a low head with the body outside.

The [propulsion comparison](PROPULSION_COMPARISON.md) and
[EDF experiment](EDF_BENCH_PLAN.md) are both deferred. The owner rejected the
approximately $825 fixture proposal and subsequently deferred all lift work.
Revisit propulsion after the carried ground hardware and operating loads are known,
adding the eventual lift assembly and any power-system changes to that payload.
This earlier model does not establish flight feasibility around stairs or dogs.

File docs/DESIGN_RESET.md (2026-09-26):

# TidyBot: three-part design proposal

> **Scope update, 2026-09-13:** [Whole-system design](SYSTEM_DESIGN.md) now controls
> cross-module layout, carried mass, lift sizing and battery decisions. This
> earlier study remains supporting evidence; its lift deferral or battery-first
> recommendation, where present, is superseded.

Draft for discussion, 2026-09-05. This is a fresh architecture proposal based on the
owner's current brief, not a build-ready specification or a flight-qualified design.
Dimensions and budgets below are provisional. The
[archived CAD](../archive/previous-design/cad/) implements the earlier TB-Port
experiment; it does not implement this proposal. Earlier specifications and decisions
are retained in the [archive](../archive/README.md) as historical reference.

**Current work order, updated 2026-09-05:** design the core and ground modules
first. Defer all propulsion selection, sizing and testing until their dimensions
and carried masses are established. The [ground module design](GROUND_MODULE_DESIGN.md)
supersedes the earlier packaging and work sequence. The owner confirmed an
automatically deployed cleaning head for the reported 50 mm sofa clearance while
the main robot stays outside. The working design is a separate low-clearance bottom
for approximately 36-inch-deep sofas accessible only from the front.

**Ground size update, 2026-09-06:** the current core/vacuum/cap placement has a
275 × 275 mm rigid footprint limit and 180 mm total height limit, including the
scanner. Flexible bristles may extend, as confirmed by the owner. Main panels
target whole 270 × 270 mm prints. The [compact placement](GROUND_PLACEMENT.md)
supersedes earlier dimensions and preferred print spans below. Other deployed
attachments and the deferred flight top still need their own envelope studies.

The robot has three externally interchangeable sections:

```mermaid
flowchart TB
    T["TOP: cap/display OR lift assembly"]
    C["MIDDLE: battery, power distribution, central logic, structural frame"]
    B["BOTTOM: wheels and cleaning hardware appropriate to the task"]
    T --- C
    C --- B
```

The middle is called the **core** to avoid confusing an electronics base with a
wheeled chassis. It has no permanent wheels. A removed core rests on a simple stand.

**Confirmed by the owner:**

- Flight-carried mass budgets, added 2026-09-14: **4.5 kg maximum** for short
  transfer flights and **3.5 kg target** for sustained hovering work, including
  the core, battery and loaded working module, excluding the lift top. See
  [mass boundaries and current gaps](MASS_BUDGETS.md).
- The propeller top must lift the entire assembly: core and attached cleaning bottom.
  Inter-floor transport is required; cleaning the stairs themselves is also of interest.
- Operation must be fully automated, including bottom and top exchanges. Plan for
  one station on each of the two floors, with automatic charging and tool handling.
- There is no fixed budget ceiling. Present costs and tradeoffs so the owner can
  challenge excessive options; reuse suitable existing inventory. This replaces
  the earlier $1,000 target and does not authorize purchases. The owner additionally
  confirms replacements are acceptable when owned parts are too heavy, large or
  underpowered; component reuse must not override the cleaning/design objectives.
- Priorities are vacuuming first, mopping second, higher-area cleaning third.
  Three dogs produce substantial hair; exceptional pickup on wood and tile is a
  design objective. There are no carpeted surfaces in the stated environment.
- The home has two floors totaling approximately 2,000 ft², split equally, all wood
  or tile. Recharging during a cleaning job is acceptable.
- The staircase is straight, with 15 reported stairs, 11-inch treads and approximately
  7.5-inch risers. Reported width is 36 inches. The left side has a 1.5-inch lip at
  approximately 37 inches vertically above the treads; the right rail projects about
  4 inches at approximately 36 inches vertically above the treads. The owner confirmed
  that the stairs themselves are 36 inches wide and the features overhang that width.
  Their detailed cross-sections and vertical extents remain to be measured/scanned.
- The landing is open wood floor with a 12-inch bookcase against a wall approximately
  36 inches from the stairs. Its position relative to the arrival path is not yet
  dimensioned. Landing on individual treads to clean is acceptable. The owner also
  proposed blowing debris down to the lower floor for subsequent vacuuming.
- The three dogs cannot be guaranteed to stay away during operation. The design
  must handle their presence and cannot depend on them learning to avoid the robot.
- The project is intended to become open source and adaptable to other homes and
  component inventories. The owner proposed camera/LiDAR environment scanning and
  an MCP server with an LLM integration for adaptive cleaning plans. These are now
  covered in the [autonomy proposal](AUTONOMY.md); no integration is implemented yet.
- Station candidates are the downstairs tile kitchen and upstairs master bedroom,
  both with substantial available space. The default station must operate without
  plumbing, using manually serviced water and waste containers at a measured interval.
  Optional kitchen water access may be added later. Routine cleaning, module swaps
  and charging remain automatic; periodic refill, emptying and maintenance are accepted.
- Available tools include soldering and crimping equipment, a multimeter, drills and
  a drill press. The owner has some electronics experience and no drone-building
  experience. TAZ 6 printing and purchased parts remain the preferred fabrication
  methods; machining beyond available tools must be discussed.

**Proposed staging assumptions:** manual, powered-off swaps are acceptable for early
mockups; local motor controllers may live with their motors; initial cleaning trials
are supervised. Manual swaps are a development step toward the required automated
stations, not the finished operation. A detached drone would not meet the confirmed
whole-assembly flight requirement. Routine onboard bin emptying and mop servicing
are included in the station study, with bulk containers manually serviced as needed.

## Where the earlier architecture drifted

| Earlier decision | Consequence | Proposed correction |
|---|---|---|
| Wheels permanently in the middle | Bottom swaps cannot directly change locomotion | Put locomotion in the bottom |
| Passive modules as a universal rule | Restricts vacuum, mop and rotor mechanisms; conflicts with local module electronics elsewhere in the documents | Share energy and central logic; allow task-specific motors, drivers and small controllers |
| Unattended swapping drove the port before robot packaging | Adds actuators and blind mating before loads and access are known | Co-design the required automatic stations and robot packaging; prove joints by hand first |
| Robot diameter limited by one print | Artificially restricts packaging | Limit each printed component, assemble larger frames if needed |
| Port must be finished before robot layout | Optimizes an interface before knowing the equipment it joins | Develop packaging, weight and a simple joint together |
| Small steel-feature margins treated as structural assurance | Omits likely failures in plastic anchorage, frame bending and retention | Verify the complete assembled load path |

There is useful work to retain: parametric CAD, small fit coupons, replaceable panels,
separation of dirty and electrical spaces, and awareness of tension loads during lift.
The legacy interface also has discrepancies: cross-pin descriptions coexist with a
grooved-post rotating lock plate, and the roadmap defers flight while the structural
ADR assumes it. These are reasons to re-baseline, not reasons to discard all the files.

## The proposed sections

| Section | Contains | Design intent |
|---|---|---|
| Core | Removable purchased battery pack, main protection/disconnect, separately protected power branches, logic regulators, central MCU, optional SBC, wiring and structural frame | Reuse expensive energy storage and central computing |
| Floor bottom | Two driven wheels with encoders, support wheel(s), motor drivers, floor-facing sensors, bumper and task hardware | Every mobile floor bottom works without core-mounted wheels |
| Cap top | Lightweight cover, optional display/buttons | Keep the first robot light and serviceable |
| Lift top | Purchased motors/propellers/ESCs, flight controller, appropriate sensors, arms, guards and attachment structure | Share the core battery only after its flight current capability is established |

Use one reusable **bottom chassis design** with internal vacuum, mop and dry-duster
cartridges. An assembled bottom remains one of the three external sections. For the
finished automatic system, build complete bottoms with their own drivetrains so the
station exchanges an entire bottom without transferring motors. Reusing one physical
drivetrain between hand-built cartridge experiments is an early development option.
A later tracked bottom could use the same core attachment, but would not replace
the required whole-assembly flight capability.

Keep vacuum blower, filter, bin and dirty-air path entirely below the core. Keep the
mop reservoir, pump, pad and all liquid plumbing there too, with a separate containment
tray and drainage away from electrical plugs. Neither air nor water crosses the
section joint. Begin the mop with a removable pad and manual wetting; add a metered
pump only after measuring drag and leakage. A dry pad can serve as a quick drivetrain
load test, but the first functional cleaning module is the vacuum.

### Vacuum design for three dogs and hard floors

Design the intake, brush and bin as a system and compare pickup on actual household
hair and grit. Do not select the blower solely by electrical wattage or a sealed
suction figure. Candidate features are a removable roller with accessible ends,
hair shielding at bearings, smooth short passages without snagging ribs, a generous
removable bin, and a washable or replaceable filter according to its supplier's
instructions. Compare a soft roller, rubber-fin roller and brushless suction head
on the same test debris before choosing the mechanism. These are test candidates,
not claims of demonstrated hair resistance.

Evaluate edge pickup, repeated-pass pickup, hair wrapping, filter loading, wheel/caster
hair buildup, cleanup time and floor marking. Check performance with a partially
loaded bin/filter, not just freshly cleaned hardware. Weigh the maximum intended
debris load for flight sizing. The mopping version also needs a bounded maximum
liquid load and control of liquid movement when the robot tilts.

A high-area duster needs a defined reach and contact-force strategy. A long tool
hanging below a flying stack can retain the three-section layout, but increases
moment, collision envelope and control demands. Hovering near a shelf and cleaning
it through contact are separate demonstrations.

## A joint we can build before owning a machine shop

Start with a broad, flat mating flange and four accessible perimeter fasteners per
face. Use purchased screws, washers and captive metal nuts in printed pockets. Broad
seating pads carry compression; the fasteners retain separation. Short printed
registration lips help hand alignment, with generous clearance so they do not fight
the fasteners. Add an asymmetric key/tab to prevent reversed assembly.

Use the same provisional structural mounting pattern on the core's top and bottom,
but key and label their electrical connections differently. Mechanical compatibility
does not imply that every module is electrically or functionally valid on either face.
Choose the bolt spacing after laying out the battery and bottom hardware. An initial
packaging sketch can explore a 160–200 mm square pattern inside a roughly 260–300 mm
body; these are study dimensions, not released CAD dimensions.

The core has upper and lower perimeter frames linked by purchased metal spacers and
bolts. Provide access to each face's screws without removing the opposite module.
For floor prototypes, reinforced printed flanges are candidates. For flight, include
metal load spreaders and evaluate bolt pull-through, plastic creep, arm roots and
frame bending: metal bolts alone do not make a printed assembly flight-ready.
Prefer purchased brackets/plates and pre-cut stock; custom drilled or machined plates
remain a decision to discuss against the actual tools available.

Power and data use separate, manually connected, polarized plugs in recessed side
pockets with strain relief. Mate with battery power isolated; no energized swapping
or pogo-pin power interface in the first prototype. A simple cradle supports the core
while changing the bottom. Tool-less retained fasteners can follow if swap frequency
justifies them. Station-actuated retention and guided electrical mating are required
development work; the hand-connected prototype does not fulfill automatic swapping.

### Required base stations

Reserve accessible structural support surfaces on the core so a station can carry
its weight before releasing the bottom. A candidate station has a guided parking
cradle, a short lift/support mechanism and storage for complete bottoms. It must
support the core independently of the wheels being removed. The station, rather
than the robot, is a candidate location for the swap actuators to limit flying mass.
The full swap mechanism and clearances need a packaging study; this is not yet a
selected mechanism.

Specify separate sequences for arrival, weight transfer to the station, disabling
module power, release, exchange, positive retention, electrical checks and departure.
Mechanical retention must remain secure without continuous actuator power. Recovery
from a failed exchange must leave every section supported. Provide separate overhead
top handling and lower bottom handling paths; both exchanges must be automatic.
Each of the two stations must accept the arriving lift top and fit a cap, then reverse
that operation before departure. Empty storage positions and the whereabouts of the
single shared lift top/caps must be tracked across floors. Tool inventory per floor
is a cost and storage choice, not a reason to duplicate the core or lift top.

Include charging and automatic transfer of onboard debris into a larger stationary
container. Study metered mop filling, dirty-water handling and pad washing/drying as
part of the later mopping phase. Use removable clean-water, dirty-water and debris
containers by default; plumbing is an optional station accessory. Measure the service
interval and pause affected jobs before supplies run out or waste capacity is exceeded.
Bulk consumable replacement and mechanical maintenance are accepted service tasks.
See [the packaging study](PACKAGING_STUDY.md) for the
proposed operating cycle and station arrangement.

## Power and control

Keep the battery in the core as requested, but make its tray replaceable. A 6S lithium
pack is a candidate, not an adopted requirement: six 3.6 V nominal cells mean 21.6 V
nominal and 25.2 V fully charged. A pack using 3.7 V nominal cells is labeled 22.2 V.
This is not a regulated 24 V supply. Set minimum operating voltage and protection
from the selected cells/pack, and verify all loads over the actual voltage range.

The cap needs only low power. The floor bottom gets its own protected motor/tool
branch. The lift top gets a separately sized high-current path; it cannot inherit the
legacy 40 W top-port allowance. Choose connectors, wire, switches and protection
from measured continuous and transient currents, voltage sag and connector heating.
Battery capacity in Ah alone says nothing about suitability for flight current.

Central logic sends motion and cleaning commands; small controllers in the modules
handle encoders and motor loops. CAN is a reasonable candidate to retain, subject to
a concrete transceiver, harness and termination design. The controller in the core can
be an MCU for early driving trials, with SBC space reserved for later navigation.
The lift module needs a dedicated flight controller rather than depending on the
navigation computer for stabilization.

Floor modules stop on lost commands and power up disabled. A flight system needs its
own explicitly designed communication-loss and low-energy responses; copying a floor
rule that instantly cuts motor power on communication loss would cause a fall.
No module may unlatch while its actuators are enabled or its weight is unsupported.
For station exchanges, disable the exchanged module's power branch and disarm the
rotors while retaining core/station control power as needed. Define flight arming and
complete retention checks before any assembled lift test.

## Printing and purchased hardware

Use the repository's 280 × 280 × 250 mm TAZ 6 envelope as the planning input and
verify the installed toolhead and usable slicer area. LulzBot's stock TAZ 6 profiles
specify a [0.50 mm nozzle](https://lulzbot.com/content/taz-6-cura-profiles).
Keep initial individual parts within approximately 250 × 250 × 230 mm to allow
margin. The assembled robot may be larger.

Print frame segments, covers, ducts, bins, motor mounts, sensor brackets and fit
coupons. PETG is a candidate for general prototypes, with temperature and load checks
around motors and batteries. Use purchased bearings, wheels/tires, gears, fasteners,
electrical plugs and a matched battery/charger. Buy the vacuum impeller/blower and
flight propellers; printed ducts and guards are different from validated rotating parts.

Do not adopt sub-0.1 mm registration as a requirement without a task that needs it.
Printed hand-alignment surfaces can be adequate after fit testing. Use washers and
through-fastened joints for significant loads; heat-set inserts are useful for covers
but should not automatically be the primary suspended-load retention.

The first mechanical mockup should require printing and ordinary fastener assembly.
The owner has the soldering/crimping tools, meter and drill press needed to explore
wiring and simple drilled brackets. No lathe, reamer, mill or hand-cut precision
grooves are assumed; any part requiring additional equipment must be discussed.

## Deferred flight feasibility reference

The owner has explicitly deferred this work until the other modules are designed
and weighed. Keep battery trays and interface cassettes replaceable, but do not
size propulsion or freeze flight-driven body dimensions now. The calculations
below retain earlier context only; they do not set the current ground design.

The following are sensitivity cases, not predictions of finished mass. All-up mass
includes the battery, core, bottom, rotor assembly, guards, fasteners and carried dirt
or water. For four non-overlapping 15-inch rotors, total disk area is about 0.456 m².

Using `P_ideal = (m*g)^(3/2) / sqrt(2*rho*A)`, with `g = 9.81 m/s²` and
`rho = 1.225 kg/m³`:

| All-up mass | Ideal hover power | Per-rotor thrust for a provisional 2:1 total thrust/weight target |
|---|---|---|
| 3 kg | 151 W | 1.5 kgf |
| 5 kg | 325 W | 2.5 kgf |
| 7 kg | 538 W | 3.5 kgf |

These are ideal aerodynamic lower bounds, not battery power estimates. They omit
profile drag, electrical losses, guards, body interference and nearby walls. The
equation follows the [NASA hover momentum model](https://rotorcraft.arc.nasa.gov/Publications/files/Johnson_AHS-SF2004.pdf).
The 2:1 target is an initial sizing assumption, not a proof of controllability.

For a concrete reference, T-Motor reports its MN4014 KV400 with a 15×5 propeller at
22.2 V producing 1.25 kgf at 126.54 W, and 2.62 kgf at 415.14 W. Four such test points
imply about **506 W at 5 kg hover thrust** and **1,661 W at maximum bench thrust**,
or roughly 23 A and 75 A. This is a scale illustration, not a selected propulsion
system or a prediction with guards installed. See the
[manufacturer's test table](https://store.tmotor.com/product/mn4014-kv400-motor-navigator-type.html).

In a square rotor layout, adjacent centers must be at least a propeller diameter
apart. Four 381 mm propellers therefore occupy at least **762 mm square**, before
blade clearance and guards, with at least about 539 mm between opposite motors.
The assembled body's clearance from the disks can increase those dimensions.
Compare the entire swept and guarded envelope with the narrowest stairwell section,
handrails, landings and required maneuvering margin. Frame diagonal alone is misleading.

The reported 36-inch stair width is 914.4 mm. Against the ideal 762 mm rotor envelope,
only 152.4 mm total, or 76.2 mm (3 inches) per side when perfectly centered, remains.
That is before guards, blade separation, rail intrusions or maneuvering margin. It
does not establish that 15-inch rotors fit operationally; smaller rotors and a lower
all-up mass need evaluation. The reported 11-inch tread depth is 279.4 mm: landing
on individual steps adds a separate wheel-support and tool-reach constraint even
if airborne transport fits the stairwell.

The owner confirmed that the projections overhang the 36-inch tread width. A
conservative envelope combining both projections is `36 - 1.5 - 4 = 30.5 inches`
(774.7 mm). Their reported heights differ by an inch and their thicknesses are unknown:
this is not yet a measured minimum clear width at one elevation. In that combined
envelope a 30-inch ideal rotor layout leaves only half an inch total before blade
separation and guards. Measure or scan the height-dependent clearance and complete
flight path; neither constant 36-inch nor constant 30.5-inch width describes it fully.

A short stair ascent may consume little energy but still needs full instantaneous
hover/climb power. For illustration, one minute at 800 W is 13.3 Wh; a small pack
must nevertheless deliver the current with control and landing reserve. Rotors also
move substantial air: the ideal disk velocity in the 5 kg example is about 6.6 m/s.
That is a reason to test dust disturbance and tool interaction, not a prediction of
air speed at a shelf.

Whole-stack lift is a confirmed requirement whose feasibility is still open. Close
mass, thrust, power, structure, indoor localization and spatial-clearance budgets.
Size for the actual cleaning bottom and permitted debris/water load. If those budgets
cannot close within the house dimensions and an acceptable cost, report the conflict
and discuss changes explicitly. A detached aircraft or mechanical stair climber
does not fulfill the current requirement.

### Dogs and autonomous flight

Treat moving animals as an ongoing operating condition. Study complete rotor access
protection, including above and below the disks, with sufficient separation under
deflection; a perimeter ring alone does not address paws or fur. Include guard mass,
airflow loss, motor heating and impact loads in testing. A cage cannot by itself
establish that a falling or colliding assembly is acceptable around animals.

The proposed controller waits on the floor when its transfer path or destination is
occupied. During flight it must continually update occupancy and have a reachable
abort/landing location with energy reserve; a preflight check alone is insufficient.
Do not treat a dog's expected cooperation or a generic obstacle-avoidance setting as
verification. As a relevant limitation of existing technology, Flyability explicitly
states that its Elios 3 return-to-home function is not supported in dynamic
environments and can miss moving obstacles in its
[automation guide](https://knowledge.flyability.com/aircraft/elios-3/elios-3-feature-details/elios-3-return-to-home-and-resume-inspection-user-guide).
That is not a claim that all flight controllers have identical limitations.

If we cannot demonstrate protection and a workable response to a dog entering the
route, autonomous stair flight in that setting remains unavailable. Automatic waiting
and reporting a blocked transfer are valid behaviors; uninterrupted flight through
an occupied route is not a promised capability.

## Work sequence and review points

1. **Package the core, everyday vacuum bottom and cap.** Position component
   envelopes, service paths and interfaces. The dedicated low-clearance bottom's
   long-reach mechanism is separate from this first build.
   Keep print segments within the TAZ 6's usable envelope. Present a consolidated
   compatible parts list and costs with the dimensioned layout.
2. **Develop the automatic joint and station support together.** Print a small
   mating sample and then the core/cap/chassis. Manual bolts and powered-off swaps
   are temporary development stages; preserve latch and connector space for the
   required automatic exchanges.
3. **Make the vacuum bottom drive and clean.** Measure traction, pickup, hair wrap,
   loaded-filter behavior, current, temperature, runtime and floor marking using
   the actual module. Record component and complete-module masses, including dirt.
4. **Demonstrate automatic docking and bottom exchange.** Integrate local control,
   retention checks, charging, emptying and floor navigation. Develop the cap
   handling interface; repeat the working station design on the other floor later.
5. **Design low-clearance, mop and duster bottoms against the same interface.**
   Include complete drivetrains, local controllers and bounded operating contents.
   Establish stowage and coverage for the front-access low head. Verify wet
   containment and pad service, and measure complete dry/loaded masses.
6. **Resume lift work with measured payloads.** Add the eventual lift hardware and
   any battery/power changes to the known core and chosen bottom. Flight selection,
   testing and high-area positioning remain deferred until this point; automatic
   inter-floor transfer remains a requirement whose feasibility is unresolved.

See [GROUND_MODULE_DESIGN.md](GROUND_MODULE_DESIGN.md) for construction details and
the measurement records. No fan test fixture or propulsion purchase is needed for
this phase. Retain earlier studies as references rather than freezing their guessed
mass, 6S battery or stair-driven body envelope into the ground robot.

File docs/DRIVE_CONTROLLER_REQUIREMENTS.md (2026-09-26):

# Wheel-drive controller selection

2026-09-06. Shopping criteria for the **BDUAV 2204-260KV rolling rig** and possible
reuse in the final wheeled bottom. The final motor choice remains open. These
criteria do not select a lift ESC or restart propulsion testing.

Prefer a **sensored FOC brushless motor controller** with local speed regulation.
FOC means field-oriented control; sensored means rotor position is measured and
used to control the motor. Both hardware interfaces and firmware support must be
established. A generic "FOC" or "30A" label does not establish these capabilities.

This list mixes required functions, integration preferences and performance that
must be measured on the actual motor. An MCU or current shunt alone does not
establish working firmware or accurate sub-amp current control. See the
[controller alternatives and installed-cost comparison](DRIVE_CONTROLLER_OPTIONS.md)
for candidates with existing servo firmware. None is yet validated with our BDUAV
motors; the ST proposal is a development platform, not a completed drive system.

## Shopping checklist

| Item | Requirement or preference |
|---|---|
| Motor type and quantity | Three-phase BLDC/PMSM; two independent motor channels, either two single-motor boards or one dual-motor controller. A brushed H-bridge does not substitute. |
| Supply | Required: operation throughout the usable 3S range, including 12.6 V fully charged and the chosen low-voltage cutoff. Preferred for possible 4S reuse: explicitly rated for 16.8 V plus braking/transient headroom; a documented operating maximum of 24 V or more is a useful search filter. This does not select 4S. A 24 V maximum does not support a full 6S pack at 25.2 V. |
| Low-speed operation | Starts under load from rest in either direction, creeps for docking, and regulates through at least 100 mechanical RPM as a proposed screening target. Normal cleaning with 60 mm wheels is approximately 48–80 RPM. Manufacturer high-speed or electrical-RPM limits are different quantities. |
| Direction and braking | Forward and reverse commanded during operation, controlled deceleration and configurable speed/acceleration limits. A setup-only direction reversal is insufficient. Verify supply behavior during regenerative braking. |
| Rotor feedback | Rotor-angle feedback supported by the actual firmware, either an onboard encoder or a supported external sensor. The current rig proposes AS5600 over I2C; an onboard or different external encoder is possible with revised wiring/mounts. A Hall-only RC-car input does not directly accept an AS5600 I2C connection. |
| Motor current control | Preferred for reusable hardware: measured phase-current control with an adjustable limit that works below 1 A. Approximately 0.1 A or finer setting increments are a screening preference, not a safe motor setting or proof of measurement accuracy. Verify sensing accuracy/noise at the intended low currents. Battery-current telemetry and a large board-overcurrent trip are different features. |
| Current capacity | Final required continuous and peak phase current are **TBD**. No basis yet to require 30 A, 40 A or 80 A. Check the real continuous rating under enclosure cooling, not only a propeller-cooled burst figure. Controller capacity is not permission to put that current through the motor. |
| Local controller | Prefer an integrated MCU with supported firmware/programming tools. A separate MCU plus driver is acceptable if the full BOM includes it. The Linux Pi issues commands/logs; the local MCU runs the fast motor loops. |
| Host connection | USB serial or documented 3.3 V UART preferred. CAN is possible with an appropriate Pi interface. PWM commands can work if the local board implements speed regulation and stopping; PWM alone does not provide telemetry. |
| Stops and faults | Disabled at boot; configurable command timeout (rig target at most 250 ms), encoder-fault handling, undervoltage and thermal handling, and a means to disable the power stage. System firmware must stop the other motor when one side faults. Board temperature sensing does not measure motor winding temperature. |
| Documentation and fit | Exact board revision, schematic/pinout, supported motor/sensor combinations, firmware and example configuration. Include connector access, wiring, encoder, MCU, programmer, cooling and power hardware in the installed size, mass and cost. |
| Availability and substitution | Owner preference added 2026-09-06: favor established distributors or ordinary retailers and avoid dependence on a manufacturer-direct purchase. Record exact revisions and procurement sources; document and test substitutes before calling them interchangeable. Availability does not waive motor-control or current-protection requirements. |

SimpleFOC distinguishes voltage control, model-estimated current and measured
current control. Its FOC current mode needs current-sensing hardware, and its
fast control loop runs locally at typically well above 1 kHz.
[Torque-control documentation](https://docs.simplefoc.com/torque_control)
Its [AS5600 interface](https://docs.simplefoc.com/magnetic_sensor_i2c) uses I2C.
The rig's two fixed-address AS5600 sensors currently connect to separate local
controller buses. A dual-controller design must resolve that address conflict.

## Lower-cost test option

A simpler encoder-based gimbal driver using voltage-mode FOC could be useful for
the BDUAV test if measured winding resistance and conservative voltage/thermal
limits support it. Current-sensing hardware is not inherent in every FOC design.
That option would require a revised commissioning plan; it would not provide the
same measured current limiting as the preferred reusable controller. The actual
BDUAV resistance remains unknown, and the conflicting ML2206B sheet is not a
substitute. Do not apply this fallback to the low-resistance iFlight motors using
the same limits. [Control-mode tradeoffs](https://docs.simplefoc.com/torque_control)

## Listing terms to check

- "Bidirectional DShot" describes command and telemetry communication; it does
  not by itself promise forward/reverse motor rotation.
  [Betaflight explanation](https://betaflight.com/docs/wiki/guides/current/DSHOT-RPM-Filtering)
- "Sensored" may mean a particular Hall-sensor interface. Check the actual
  connector, signal type and firmware before choosing an encoder.
- "FOC driver" or "SimpleFOC-compatible" may describe only a power-stage board.
  Check whether the MCU, current sensing and firmware are included.
- "30 A continuous" is neither a minimum needed here nor a small-motor current
  setting. An oversized sensing range may require extra attention to low-current
  resolution and calibration.

Useful search terms: **sensored FOC BLDC controller external encoder current
control 3S**, or **SimpleFOC controller integrated MCU current sensing**.

The [B-G431B-ESC1](https://www.st.com/en/evaluation-tools/b-g431b-esc1.html) is one
candidate because it includes an MCU, three-phase stage, sensor support and
current shunts. It still needs external encoders, custom sensored firmware and
verification of low-current control with the BDUAV motors. Its published 40 A
peak was tested with propeller-forced cooling; it is not our enclosed rating.
Alternatives should be compared against this checklist and the
[complete rig hardware proposal](../design/experiments/drive_rig/HARDWARE.md).

If the final robot uses brushed gearmotors, choose an appropriate H-bridge drive
instead. Passing this checklist establishes a candidate, not proven motor torque,
bearing life, thermal performance or automatic-cleaning suitability.

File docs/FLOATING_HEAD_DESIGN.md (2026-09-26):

# Floating vacuum and mop heads — revision M

**Weight-review update:** the owner challenged this candidate's increasing
mass. The [corrective design direction](MASS_OPTIMIZATION_REVIEW.md) now takes
priority over the detailed-carriage work proposed below. Preserve these motion
and load findings as comparison evidence while evaluating simpler construction.

The [N fixed-mount alternative](FIXED_DRIVE_COMPARISON.md) now quantifies that
tradeoff. Its sampled head requirements exceed M's travel and tilt limits;
do not reuse M's clearance results for a rigid drivetrain. The next passive
head comparison must include the larger motion before claiming a mass saving.

M establishes a **motion and load requirement for the mounts** and a revised
packaging proposal. The original static layout cannot accommodate floating
heads. The revised allocations pass the sampled clearance checks, but the
guide/lift hardware and tighter drive packages still need detailed CAD. These
files are review models; there are no new parts to print or order.

Start with the [interactive views](../design/system/output/floating_heads.html),
[calculation report](../design/system/output/floating_heads.md), or
[vacuum working CAD](../design/system/output/floating_heads_vacuum_working.FCStd)
and [mop working CAD](../design/system/output/floating_heads_mop_working.FCStd).
Each CAD scene also has a STEP export and a separate `_raised` pose.

## What must move

**Vacuum:** float the complete removable cassette, including its roller,
stationary cutter restraint, guard, drive motor, transmission and motor driver.
This keeps the motor/roller relationship fixed during head motion. The blower,
bin and main dirt duct remain attached to the bottom chassis. Retain a smooth,
short compliant connection at the rear outlet and a separate flexible service
harness. The flex-joint allocation is excluded from rigid collision checks;
its sealed deformation and force must still be established.

Keep the two service levels already agreed: the TriCut/plain roller comparison
within a compatible cassette, and complete cassette replacement for another
brush mechanism. The station exchanges the complete wheeled bottom. It does
not dismantle a brush cassette. Changing cassette mass requires a recorded
counterbalance setting as well as its brush speed/contact settings.

**Mop:** float the pad carrier, eccentric mechanism and motor together. Inside
that floating assembly, only the pad and its immediate oscillating plate make
the 3 mm peak-to-peak lateral cleaning stroke. The tank, pump and lift actuator
remain fixed. Keeping the drive with the pad avoids requiring an unmodeled
telescoping shaft or articulated drive across the vertical motion.

This is heavier than floating the textile alone, but that alternative needs a
complete moving drive interface before any mass saving can be credited.

## Proposed mount architecture

Use a chassis-mounted vertical carriage carrying a limited-angle head pivot.
The carriage provides vertical movement; a two-axis pivot lets the cleaning
surface follow small pitch/roll differences. Spring force acts on the carriage
through an adjustable equalizer. The head-to-carriage joint must carry yaw,
scrubbing and roller reaction loads while allowing the two specified tilt axes.
Its guides and pivot need guards against hair and mop splash.

| Requirement | Vacuum | Mop |
|---|---:|---:|
| Working vertical motion from current floor reference | −2 to +10 mm | −2 to +10 mm |
| Working pitch and roll allowance | ±1.5° each | ±1.5° each |
| Raised position, level relative to chassis | +16 mm | +16 mm |
| Moving dry hardware, including moving mount allowance | 512 g | 282 g |
| Extra moving contents | None modeled | 0–100 g pad water |
| Initial normal-force target | 3 N | 8 N with 50 g pad water |
| Effective total spring rate target | 0.12 N/mm | 0.16 N/mm |
| Signed preload at reference position | 2.02 N upward at +4 mm | 4.74 N downward at +1 mm |

These are **mechanism requirements, not selected spring specifications**. The
low effective rate and adjustable preload need a packaged spring/lever design.
The calculation treats vertical translation and floor alignment as ideal; it
does not prove that the proposed carriage and pivot fit, that they do not bind,
or that they balance the off-centre motor weight and cleaning moments. Locating
the actual pivot will also introduce lateral motion that must be added to the
clearance audit. Do not cut a slot and infer that the modeled freedom exists.

The vacuum head weighs about 5.02 N before touching the floor. Adding downward
springs would defeat a 3 N contact target. Upward counterbalance reduces its
mechanical contact force while letting it follow the floor. The plain roller
may need substantially less counterbalance; select its setting from installed
mass, not a presumed equal bare-roller weight.

The mop's wet reference moving weight is about 3.26 N. Its spring system adds
about 4.74 N at the reference position to reach 8 N. That is approximately
1.09 kPa over the 230 × 32 mm pad area. Neither this pressure nor the vacuum's
3 N target has been validated for cleaning performance.

At the existing 15 Hz design frequency, a 1.5 mm eccentric has about 13.3 m/s²
peak acceleration. If the existing 105 g pad allowance all oscillates, it
produces about 1.4 N peak inertial force dry and 2.7 N with 100 g retained water,
before any additional oscillating mount mass. A counterweight tuned dry cannot
cancel every wet-pad condition. Keep the vertical force adjustment independent
of the oscillator and check vibration isolation before committing the scanner
mounts. The M equilibrium calculation is static and excludes those forces.

## Lift and retention

The lift should operate through a lost-motion connection: slack during normal
floor following, taking up only when commanded to raise. It must level the
head before reaching the +16 mm stop. A mechanical capture supports it raised;
the actuator is not intended to remain stalled. Captive lower stops retain the
head when the entire robot is lifted. Position sensing must distinguish a head
resting on the floor from a mechanically captured head.

Stop the roller or mop oscillator before raising; stop water before lifting
the mop. Verify raised capture before module exchange or any future flight.
A caught head must cause a stop/recovery action rather than increased lift
force. The exact link ratio, lift load, release behavior and capture hardware
are still to design.

Retain the existing **PQ12-100-6-R envelope as a reference**. Its manufacturer
lists 20 mm stroke, 19 g mass and 10 mm/s no-load speed. A 16 mm head lift does
not yet imply 16 mm actuator movement or a demonstrated lift time. The 62 g
installed allowance includes the actuator, links, supply and switches. The
manufacturer currently lists it on backorder; this study adds no purchase.
[Actuonix product data](https://www.actuonix.com/pq12-100-6-r).

## Necessary packaging changes

Coordinates remain X left-to-right, Y front-to-back and Z upward in the nominal
chassis frame. These changes are an M overlay; the previous files are preserved.

| Allocation | M proposal | Reason |
|---|---|---|
| Vacuum cassette | 230 × 60 × **48 mm**, same floor reference | +16 mm raised head must clear side rails starting at Z=65 mm |
| Vacuum drive | **71 × 60 × 29 mm**, minimum [32,6,50] | Clears side rail, raised power shelf and neighbouring electronics while tilting |
| Vacuum power shelf and its equipment | Raise **18 mm** | Creates room for the motor to move with the cassette |
| Vacuum drive controller, blower driver and bottom supervisor | Raise **18 mm** | Clears the moving cassette |
| Shared Pi bay | Raise **20 mm**, new Z=107…141 mm | Makes room over the revised front electronics |
| Shared front camera | Raise **16 mm**, new Z=70…101 mm | Clears the lifted head while staying below the front frame rail |
| Front-right near sensor | Move X from 235 to 250 mm | Clears the raised Pi bay |
| Mop motor/crank allocation | **32 × 27 × 83 mm**, minimum [105,162,24] | Clears battery, lidar mount and rear pump through motion |
| Mop tank | Raise **18 mm**, new Z=41…121 mm | Clears lifted/tilted pad while retaining tank volume |
| Mop lift allocation | Raise **15 mm**, new Z=42…71 mm | Clears the raised pad |
| Cap roof reservation | Raise **6 mm** to 153.1 mm | Covers the raised vacuum power/fan bay; lidar still sets overall height |

The smaller envelopes need actual hardware fit checks. In particular, a listed
45.1 mm brush dimension inside a 48 mm head leaves only 2.9 mm gross difference;
this is **not a verified guard/cutter/brush-to-floor stack**. A 25 mm motor in a
29 mm drive height leaves only 4 mm for surrounding structure/clearance. The
mop's narrow drive bay similarly needs a real motor, eccentric, wiring and
support arrangement. If these stacks fail, revise the nearby packaging instead
of reducing required guards or brush clearance.

The Pi/camera changes affect the shared core, including other bottoms. M checks
vacuum and mop integration only; sofa/duster interfaces, camera view and
removal paths must be rechecked before adopting those shared changes. Existing
camera/LiDAR performance and occlusion assumptions are not revalidated here.

The power shelf now needs taller structural supports and a renewed thermal and
harness check. Raising the tank needs positive retention and a revised leak
tray. The clearance model does not contain these new brackets.

## Loads, clearances and mass accounting

The model separates fixed chassis mass, each moving wheel pod and the complete
moving head. Tank water stays with the tank; pad water moves with the mop.
It solves head position/contact force and wheel spring equilibrium together.
Contents and caster direction change during use; wheel shim settings remain
fixed after module calibration.

| Result | Vacuum | Mop |
|---|---:|---:|
| Nominal loaded planning mass | **5.316 kg** | **4.954 kg** |
| Added mount/lift/riser allowance | 174 g | 98 g |
| Wheel shim proposal, left/right | 3.50 / 3.00 mm | 3.50 / 2.75 mm |
| Working head translation | +2.42…+3.69 mm | −0.23…+0.14 mm |
| Net floor support at head | 1.92…3.89 N | 6.29…9.36 N |
| Total normal load on drive wheels | 40.45…45.45 N | 29.53…33.10 N |
| Minimum raised-head floor clearance | 10.47 mm | 14.52 mm |
| Maximum height including 2 mm reserve | 176.01 mm | 177.55 mm |

The mass totals retain K's complete hardware allowances. M adds guide/pivot
and riser allowances plus one vacuum lift; the existing mop lift stays counted
once. Some old head allowances already included suspension, so there may be
overlap to remove when the hardware is resolved. **No weight saving is claimed.**
I's alternative scanner masses are still not substituted into K's totals.
Some aggregate power/structure CG rows lack component-level positions; their
placement remains an allowance. These are not measured assemblies or final
flight inputs.

The operational sweep has 1,512 working cases and 168 raised cases. It varies
contents, 24 caster directions, ±20% effective head-spring rate and ±1 N net
parasitic force. These are project sensitivity bounds, not supplier tolerances
or measured guide/duct forces. All modeled wheel supports stay positive and
clear their stops; all required working poses remain within the selected travel.

A separate **0–5 N suction-force sensitivity** raises gross vacuum floor
contact to as much as 8.89 N. Pressure pushing the head down and the resulting
floor contact act in opposite directions on the whole robot. With coincident
resultants, they increase local contact/drag without unloading the chassis by
that same 5 N. The calculation keeps net head support separate from gross
contact. It does not establish the pressure footprint, its moment, skid/brush
friction, or available wet-floor traction.

There are 28 geometric poses per module: 27 combinations of translation and
tilt, plus the level raised stop. The mop pad also receives ±1.5 mm oscillation
offsets. The proposed transformed bounding boxes have no overlaps with the
checked fixed allocations and remain within 275 mm in X/Y. This is a finite,
conservative envelope check, not a complete assembly collision certification.
K's detailed moving pod, new guide/lift/retention hardware, cable motion and
the deforming air joint still need inclusion.

The 10.47 mm vacuum raised clearance has little margin over a 10 mm threshold,
and is measured above a **flat floor** in the static model. It does not prove
step crossing, which changes support points and chassis attitude. Retain the
L requirement to raise the anti-tip mounts 10 mm; they remain clear in this
sweep, but their new brackets are not designed. L's wheel-spring tolerance
failures also remain open despite nominal M shim checks passing.

## Next deliverable

Detail the **vacuum cassette and its carriage first**: real roller/drive-end
and guard stack inside the 48 mm head, motor/transmission inside the narrowed
drive bay, then guide/pivot, counterbalance, captive stops and lift latch.
Include their actual motion, side loads, duct stiffness and mass in the model.
If the component stack needs more room, revise the overhead layout before
releasing a full head print. Apply the proven carriage approach to the mop only
after its oscillating stage and wet-pad load range are accounted for.

Inputs: [floating_heads.json](../config/floating_heads.json).
Checks and remaining limits: [validation record](../design/system/output/floating_heads_validation.md).
Regenerate calculations with `python3 design/system/floating_heads.py` and CAD
with `freecadcmd design/system/export_floating_heads_freecad.py`.
Run the system test suite with
`python3 -m unittest discover -s design/system -p 'test_*.py' -q`.

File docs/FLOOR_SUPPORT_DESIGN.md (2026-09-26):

# Wheel suspension and caster support — H study

Follow-up: the [I height/mounting overlay](HEIGHT_AND_CASTER_LAYOUT.md) retains
this travel and passes the sampled height screen with a C1 lidar and revised
connector layout. It also replaces the assumed caster fitting height below with
a documented fitting and moves adjacent equipment. Caster pull-out retention
remains open. This H document and its artifacts retain the earlier failing case.

The next candidate uses **rear-mounted suspension pivots and a shallow caster
saddle**, with fixed rails carrying both their loads and the floor electronics.
The [interactive mechanism view](../design/system/output/floor_support.html)
shows wheel travel and the resulting height screen. The
[generated report](../design/system/output/floor_support.md) contains dimensions,
load calculations, stock accounting and unresolved connections.

The wheel axle moves 3 mm forward to leave room for the pivot supports ahead of
the mop mechanism. A 40 mm leading arm preserves 10 mm upward travel. A 6 mm
smooth pin with replaceable bushings is the current candidate: the earlier 4 mm
pin fails the preliminary impact bending screen once the separate bump-stop
force is included. This does not qualify the motor output shaft or its bearings
for the same load.

The spring acts closer to the pivot than the wheel. A 5 N/mm spring therefore
provides approximately 0.8 N/mm at the wheel. The spring needs module-specific
preload, a guided/pivoting seat and separate mechanical travel stops. These are
component requirements, not a selected spring or finished moving pod.

The caster's 40 mm-wide support uses a flat 3 mm aluminum plate, attaching
to a rear crossbar through bolted angles. It reserves another 5 mm above the plate
for retaining hardware. Its separate stem fitting matters: the 2.5 mm added
height case leaves only **1 mm beneath the vacuum/mop bin allocation**. A 5 mm
fitting fails that space. The reference fitting is an assumption pending an exact
manufacturer drawing; the bare caster's rolling load rating does not establish
its retention during lifting.

**The full height requirement is still open.** The previous 179.1 mm result
describes the nominal suspension pose. Sampling an ideal three-support model
with 2.5 mm downward wheel travel produces heights up to **181.9 mm**, beyond the
180 mm constraint. That travel has not been adopted. Sensor/cap placement and
the full suspension envelope must be resolved together, with manufacturing
clearance. Removing wheel travel silently would not resolve that design tradeoff.

Candidate stock routes clear the existing vacuum, mop and sofa allocations;
the candidate blanks also avoid volumetric overlaps with each other. Their
mounting angles, fasteners, the moving tray, stop fingers, cable loops and all
four module-seat connections remain incomplete. The existing **G complete
mass estimates remain unchanged**. Partial stock masses cannot establish a
replacement frame weight or justify removing the existing power carrier.

The manufacturer review also corrects the earlier drive torque screen:
Pololu's gearbox guidance limits continuous loading to **0.392 N·m**, below the
earlier 0.539 N·m fraction-of-stall estimate. Its general 25%-of-stall-current
guidance corresponds to 1.25 A; treat the existing 2 A setting as a bounded
transient setting, with motor thermal limits still applying.
[Manufacturer guidance](https://www.pololu.com/product/4846).

Review artifacts:

- [Editable inputs](../config/floor_support.json) and
  [candidate stock ledger](../design/system/output/floor_support_stock.csv).
- Reference CAD: [vacuum](../design/system/output/floor_support.FCStd),
  [mop](../design/system/output/floor_support_mop.FCStd),
  [sofa](../design/system/output/floor_support_low.FCStd),
  [full bump](../design/system/output/floor_support_bump.FCStd),
  [candidate droop](../design/system/output/floor_support_droop.FCStd).
  Each has a same-named STEP file. Wireframes show functional allocations and
  mechanism routes; these are not complete motor cartridges or fabrication files.
- [Verification record](../design/system/output/floor_support_validation.md).

Reproduce from the repository root:

```sh
python3 design/system/floor_support.py
python3 -m unittest discover -s design/system -p 'test_*.py' -q
freecadcmd design/system/export_floor_support_freecad.py
```

Next, resolve the suspension height envelope and the retained caster fitting,
then finish moving-pod and rail/seat fasteners before replacing the frame/carrier
allowances. No purchase or print is needed for this review.

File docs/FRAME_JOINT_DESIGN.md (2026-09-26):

# Core frame and module joints — revision G candidate

The later [I height/mounting candidate](HEIGHT_AND_CASTER_LAYOUT.md) resolves
the sampled height conflict with a different lidar and connector layout. It
preserves this frame's mechanical seat locations; connector mating still changes.

Follow-up: the [H wheel/caster support study](FLOOR_SUPPORT_DESIGN.md) adds
mechanisms and load checks while retaining G's complete mass accounting. Its
proposed droop exceeds 180 mm in some modeled support poses. The 179.1 mm height
below is the nominal pose, not a verified full suspension envelope.

The next mechanical candidate uses **four short sections of rectangular aluminum
tube at the core corners**, connected by aluminum strips standing on edge. Each
tube connects the upper and lower module seats through continuous metal walls.
This replaces the earlier frame allowance with dimensioned stock and a first
load calculation.

The result is **159 g for the core metal frame and mounting hardware**, compared
with the previous 145 g allowance. That adds about **14 g** to each complete
configuration. This pass does not establish a weight saving. The 160 g printed
trays/ribs and 130 g locking-mechanism budgets remain; neither has been reduced
without a complete replacement design.

Start with the [generated design report](../design/system/output/frame_joints.md),
[corner section drawing](../design/system/output/frame_joints.svg), or
[core-only FreeCAD model](../design/system/output/frame_joints_core.FCStd).
The [editable inputs](../config/frame_joints.json) and
[core hardware ledger](../design/system/output/frame_joints_hardware.csv) include
stock sizes, fasteners, assumptions and mass accounting.

Corner section and load path

The corner stock reference is a 25.4 × 38.1 mm rectangular tube with 3.175 mm
walls, cut into four 18 mm lengths. It uses crosscuts and drilled holes; there is
no longitudinal slot or machined central block. Existing drill-press capability
is useful. A metal-cutting saw/vice or supplier-cut stock, countersink and the
steel-slider cutting method remain to arrange before fabrication.

The steel sliders are 20 × 18 × 2 mm, with an 8 mm outward stroke. The complete
stroke stays inside the nominal 275 mm width. Metal bearing pads keep the
sliders clear of the assumed tube corner radius under load. Actual stock radii,
keeper/guide construction, positive pawls, springs, wear and fastener clearances
remain to qualify; the CAD is not a released latch.

The inherited **600 N factored axial requirement** is retained. Calculations
check four-way load sharing and a 300 N per-corner case for unequal sharing.
The 3.175 mm wall passes the simplified bending screen; the thinner alternatives
in the report fail that screen. These calculations do not establish fatigue life,
local hole strength, joint retention or safe flight.

The top seat rises from 123 to **124.1 mm**. Upper core components rise 1.1 mm,
bringing the modeled overall ground height to **179.1 mm**. The top mounting
fixture and station mating datum must use the new height; previous top-seat
fixtures cannot be assumed interchangeable.

Small placement changes clear the rails and sliders. The Pi and pack-protection
bays move inward, while the rear bins/filter bay gain left-side clearance. The
filter element retains its full size. The vacuum, mop and sofa capacity targets
remain **500, 350 and 300 mL** respectively. They pass the declared wall/reserve
volume screen, but the mop and sofa margins are small: detailed ports, baffles,
seals and evacuation geometry must preserve those capacities.

The shared floor-power bridge now has a clear replacement route after splitting
the controller/supervisor carriers and moving the full sofa feed-drive bay 5 mm
forward. **The existing F carrier remains installed and fully counted.** The
replacement bridge's fixed wheel-pivot and caster-support attachments still need
design before we remove those supports or credit their mass. This distinction
keeps the weight estimate honest while preparing the next chassis layout.

| Complete loaded configuration | G nominal estimate |
|---|---:|
| Vacuum/drive + cap | 4.777 kg |
| Mop/drive + cap | 4.491 kg |
| Sofa vacuum/drive + cap | 5.056 kg |
| Airborne duster + four-propeller reference top | 5.017 kg |

G inherits the power partition from [revision F](CORE_POWER_PARTITION.md) and
the duster mechanism from [revision E](AIRBORNE_DUSTING.md). The older outputs
remain comparison evidence. The battery, cleaning payloads, guards, sensor count,
electrical loads and mission reserves are unchanged. Flight remains unqualified.

CAD allocations, each with a same-named STEP file:

- [Core frame and sliders](../design/system/output/frame_joints_core.FCStd).
- [Vacuum configuration](../design/system/output/frame_joints.FCStd).
- [Mop configuration](../design/system/output/frame_joints_mop.FCStd).
- [Sofa configuration](../design/system/output/frame_joints_low.FCStd).
- [Airborne duster](../design/system/output/frame_joints_duster.FCStd).

Reproduce from the repository root:

```sh
python3 design/system/frame_joints.py
python3 -m unittest discover -s design/system -p 'test_*.py' -q
freecadcmd design/system/export_frame_joints_freecad.py
```

See the [verification record](../design/system/output/frame_joints_validation.md)
for what was checked and what remains untested. No purchase or print is needed
for this review. The next chassis task is the fixed suspension-pivot brackets,
caster bridge and their connections to the module seats.

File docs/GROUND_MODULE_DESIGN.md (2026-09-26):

# Ground modules: core, vacuum and cap

> **Sofa update, 2026-09-14:** the [resident attachment comparison](SOFA_ATTACHMENT.md)
> supersedes the dedicated-sofa recommendation below as the direction to develop.
> One extension stays at each floor dock; the ordinary vacuum shares its drives,
> bin, filter and blower, and carries only its retained interface during flight.

> **Scope update, 2026-09-13:** [Whole-system design](SYSTEM_DESIGN.md) now controls
> cross-module layout, carried mass, lift sizing and battery decisions. This
> earlier study remains supporting evidence; its lift deferral or battery-first
> recommendation, where present, is superseded.

**Current follow-up:** the [next vacuum-module pass](VACUUM_MODULE_NEXT_PASS.md)
records the ordered drivetrain and revises the head/bin/air-path proposal for
72 mm wheels and 4–10 mm floor transitions. The
[cassette plan](VACUUM_CASSETTE_PLAN.md) defines replaceable heads and the first
TriCut/plain-brush comparison. Inventory-based placements below remain historical
references where they differ from these follow-ups.

2026-09-05. **Current design phase.** The owner has deferred propulsion selection,
lift sizing, fan testing and the EDF stand until the other modules are designed
and their carried masses are known. Whole-assembly lift remains a later requirement.
This document supersedes the earlier concept's ground packaging and work order.
It specifies the arrangement and interface responsibilities. The first
[dimensioned placement](GROUND_PLACEMENT.md) now provides proposed envelopes,
service paths and joint zones; electrical ratings and fabrication drawings are
not released yet.

## Current overall envelope

The compact [placement](GROUND_PLACEMENT.md) uses a **275 × 275 mm rigid body
including wheels, with a 180 mm total height limit including LiDAR**. Flexible
bristles may extend, explicitly confirmed by the owner. The modeled height is
178 mm. Main panels target whole 270 × 270 mm prints; actual toolpaths and
structural sections remain to check. This replaces earlier larger packaging.
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

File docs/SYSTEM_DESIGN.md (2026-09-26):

# TidyBot whole-system design — revision C review

**T bottom-frame decision, 2026-09-15:** [reject the surrounding-frame integration](BOTTOM_CHASSIS.md)
that retains N's separate motor supports. The complete local estimate rises about
55 g and the head/service path has obstructions. This is not an adopted weight
increase. T also includes the 30 g caster-hardware correction omitted from the
older N/O ledger. The 681 g old support scope is smaller than the 775 g vacuum
deficit: a real chassis reduction must be accompanied by changes elsewhere.
Next compare direct motor support in a structural tray and lighter implementations
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

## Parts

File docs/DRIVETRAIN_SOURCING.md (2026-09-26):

# Drivetrain sourcing

2026-09-12. Supplier cross-reference for the proposed ground drivetrain. Prices
are USD listing snapshots before shipping, tax and any tariffs; stock statements
are not confirmed delivery dates. The [machine-readable source list](../config/drivetrain_sources.csv)
contains alternative suppliers and alternative components, **not a cumulative
shopping list**. Assembly hardware and power electronics are not yet complete.

## Recommendation

Keep the compact Pololu 25D encoder motors, RoboClaw controller and 72 mm Hogback
wheels as the preferred design candidate from the
[component recommendation](GROUND_COMPONENT_RECOMMENDATION.md). These can be
purchased through distributors, although availability has qualifications:

| Component / manufacturer part | Supplier and supplier SKU | Unit price | Listing status |
|---|---|---:|---|
| Pololu encoder gearmotor **4846**, two required | [DigiKey](https://www.digikey.com/en/products/detail/pololu/4846/10450248), **2183-4846-ND** | $56.95 | Marketplace; stock reported, shipped by Pololu |
| Same Pololu motor | [RobotShop](https://www.robotshop.com/products/pololu-12v-751-metal-gear-motor-hp-48-cpr-protected-encoder), **RB-Pol-840** | $56.95 | Re-stocking soon |
| Basicmicro RoboClaw 2x7A **IMC404**, one required | [RobotShop](https://www.robotshop.com/products/roboclaw-2x7a-6-34vdc-regenerative-motor-controller), **RB-Bat-22** | $79.95 | Re-stocking soon |
| Same RoboClaw controller | [Pololu](https://www.pololu.com/product/3682), **3682** | $79.95 | Backorder; owner also confirmed unavailable |
| Same RoboClaw controller | [ServoCity](https://www.servocity.com/roboclaw-2x7a-motor-controller/), **IMC404** | $79.99 | Listed without an out-of-stock label; dispatch unverified |
| Same RoboClaw controller | [Basicmicro](https://www.basicmicro.com/RoboClaw-2x7A-Motor-Controller_p_55.html), **IMC404** | $79.95 | Manufacturer-direct; explicitly reports in stock |
| Hogback wheel **3626-0014-0072**, two required | [RobotShop](https://www.robotshop.com/products/servocity-hogback-traction-wheel-72mm-diameter-50a-durometer), **RB-Sct-3644** | $8.99 | On demand; not normally stocked |
| Sonic 4 mm hub **1309-0016-0004**, two proposed | [RobotShop](https://www.robotshop.com/products/1309-series-sonic-hub-4mm-bore), **RB-Sct-1456** | $6.99 | On demand; not normally stocked |

The DigiKey motor listing offers distributor checkout, but does not establish a
second independent stock location: Pololu also identifies this relationship on
its [distributor page](https://www.pololu.com/product/4846/distributors).
[ServoCity](https://www.servocity.com/hogback-traction-wheels/) is another purchase
route for the same wheel, rather than a different interchangeable wheel design.
The nominal wheel-to-hub interface has now passed the supplier CAD check below.
Order the wheels and hubs together; physical wheels are not required to finish
the remaining bracket design.

**Controller availability follow-up:** the owner confirmed backorders at Pololu
and RobotShop. Basicmicro's product and category pages explicitly report stock;
ServoCity provides another US reseller listing, but no dispatch date was verified.
The direct manufacturer route does not satisfy distributor sourcing by itself.
Check ServoCity's fulfillment before ordering if distributor purchase is the
priority. These are purchase routes for IMC404, not a controller redesign; confirm
the supplied hardware revision before releasing its printed mount. The 2x15A
version was also backordered at Pololu and RobotShop when checked, so it does
not currently resolve those distributors' availability problem.
[Pololu 2x15A](https://www.pololu.com/product/3683) and
[RobotShop 2x15A](https://www.robotshop.com/products/roboclaw-2x15a-6-34vdc-regenerative-motor-controller).

## Alternatives with conventional DigiKey and Mouser listings

These are independent alternatives: either controller architecture could drive
either brushed motor candidate after appropriate configuration and sizing.

| Component | DigiKey | Mouser | Unit price at either listing |
|---|---|---|---:|
| DFRobot **FIT0185**, 12 V, 83 RPM encoder gearmotor | [1738-1105-ND](https://www.digikey.com/en/products/detail/dfrobot/FIT0185/6588527) | [426-FIT0185](https://www.mouser.com/en/ProductDetail/DFRobot/FIT0185?qs=lqAf%2FiVYw9g4vmxHGv4taQ%3D%3D) | $16.50 |
| DFRobot **DFR0601**, dual brushed-motor driver | [1738-DFR0601-ND](https://www.digikey.com/en/products/detail/dfrobot/DFR0601/10279757) | [426-DFR0601](https://www.mouser.com/ProductDetail/DFRobot/DFR0601?qs=PzGy0jfpSMt2BcSAELKXOA%3D%3D) | $29.38 |

All four listings reported distributor stock when reviewed. Check delivery and
price when ordering; this is not a stock reservation.

**FIT0185 motor:** the manufacturer documents a 37 mm body, 205 g mass and 6 mm
D shaft, versus 25 mm, 104 g and 4 mm for the Pololu. Two motors add about
202 g before changes to brackets and hubs. With 72 mm wheels, its nominal
83 RPM no-load speed corresponds to 0.31 m/s; loaded speed will be lower.
It requires a different mounting plate, 6 mm hub and encoder configuration.
It is not a drop-in replacement within the 275 mm chassis.
[DFRobot specifications](https://wiki.dfrobot.com/fit0185/) and
[Pololu specifications](https://www.pololu.com/product/4846/specs).

FIT0185 remains a conditional alternative: the current manufacturer table gives
stall torque, without an established continuous-duty torque rating. Do not use
the advertised 45 kgf·cm stall figure as a working load. Obtain the manufacturer's
continuous-load guidance before selecting it for the cleaning robot; the main
design does not depend on another characterization rig. The Pololu's documented
gearbox continuous-load guidance is one reason it remains preferred.
[FIT0185 product page](https://www.dfrobot.com/product-633.html) and
[Pololu load guidance](https://www.pololu.com/product/4846).

**DFR0601 controller:** this is a 6.5–37 V, two-channel H-bridge rated for
12 A continuous per channel, with 3–5 V control inputs and a
50 × 50 × 12.5 mm envelope. It is a power stage, whereas RoboClaw also processes
encoders and runs velocity loops. DFR0601 does not document programmable
motor-current limits or current telemetry.
[Manufacturer specifications](https://www.dfrobot.com/product-1861.html/).

A [Raspberry Pi Pico 2, SC1631](https://www.digikey.com/en/products/detail/raspberry-pi/SC1631/24627136)
is a distributor-stocked MCU candidate at $6.12. DFR0601 plus Pico 2 is $35.50
for those two boards only. Matching RoboClaw's intended role additionally needs
encoder interfacing, velocity-control firmware, current sensing/protection,
command timeout and a defined hardware disable state. Provide suitable logic
levels for the selected encoder and MCU. DFR0601's floating control inputs read
high; design explicit startup states. Board overtemperature protection is not
a motor-winding current limit.
[DFR0601 interface documentation](https://wiki.dfrobot.com/dfr0601/docs/18917).

Both architectures need a separate Pi supply and a braking-energy plan. A driver
accepting 4S battery voltage does not make a 12 V motor safe at unrestricted
4S drive. Complete those details during power integration.

## Wheels and interchangeability

### Wheel-to-hub check, 2026-09-12

FreeCAD inspection and assembly of the manufacturer's STEP files for
**3626-0014-0072** and **1309-0016-0004** confirm:

- Four shared mounting positions form a 16 × 16 mm square. The wheel has
  nominal 4 mm through holes; the hub has M4 threaded holes.
- The hub's 14 mm diameter, 2 mm long centering boss mates with the wheel's
  nominal 14 mm bore. The models have zero volumetric intersection when seated.
- The hub body is 8 mm long; the wheel mounting web is 4 mm thick. With the hub
  back at axial zero and the web seated at +8 mm, the tire spans -4 to +20 mm.
  Its inward overhang must be included in the printed bracket design.
- Pololu publishes a 12.5 mm long output shaft. Relative to the hub's 8 mm body,
  this leaves 4.5 mm for bracket/clearance consumption before full body engagement
  is lost. Placement and clamping on the actual D shaft remain assembly checks.

This establishes nominal mating of the purchased wheel and hub, not a finished
motor cartridge. Bracket shape, clamp access, fastener selection, shaft loading
and the complete 275 mm chassis envelope still need integration. Physical parts
will validate manufacturing tolerances during normal assembly; they are not a
prerequisite for these CAD checks. The practical wheel order is **two wheels plus
two hubs**. Wheels alone do not attach to the motor shafts.

[Hub CAD download](https://www.gobilda.com/content/step_files/1309-0016-0004.zip),
[wheel CAD download](https://www.gobilda.com/content/step_files/3626-0014-0072.zip),
and [motor shaft dimensions](https://www.pololu.com/product/4846/specs).

### Traction and other wheel options

The Hogback's specified silicone tread and 50A hardness make it a reproducible
candidate, but there is no published wet wood/tile traction coefficient. Its
performance on the intended cleaner film still needs a brief assembled-robot
check. Keep the wetted mop pad behind the normal wheel contacts and account for
crossing previously mopped areas.
[Wheel specification](https://www.gobilda.com/hogback-traction-wheel-72mm-diameter-50a-durometer/).

Two widely catalogued wheels do not replace it directly:

- [DFRobot FIT0199-R](https://www.dfrobot.com/product-653.html): the manufacturer
  allows tire material and tread pattern to vary. That is unsuitable as our
  reproducible traction reference.
- [DFRobot FIT0500](https://www.dfrobot.com/product-1535.html): an 80 × 17 mm
  silicone wheel, but its TT-motor mounting profile differs from both proposed
  D shafts. It would need a separately designed adapter.

For open-source acquisition, publish manufacturer part numbers, supplier SKUs,
drawings and interface requirements together. Keep exact-part supplier links
separate from substitute-part profiles. Proposed profiles should record motor
plate/hub geometry, wheel diameter, encoder counts per output revolution,
voltage/current limits and controller interface. A generic “25 mm gearmotor”
or an Amazon title is insufficient to establish interchangeability.

Next, package the preferred drive assembly and reserve a replaceable motor plate
and controller adapter. A 37 mm alternate remains conditional on continuous-load
documentation and fit. No new motor plates, controller firmware or replacement
fabrication files are released by this sourcing document.

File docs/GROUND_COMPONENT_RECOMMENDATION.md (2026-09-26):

# Ground robot component recommendation

2026-09-12. Recommendation for the robot, with component choices driven by the
cleaning requirements. The owner has asked us to assume that owned components
requiring basic performance characterization will not be suitable. The BDUAV
drive rig is now an optional experiment, not a prerequisite for robot design.
The owner subsequently reported two selected motors and the dual controller on
the way. Wheel/hub purchases have not been reported. Fabrication remains pending
the placement and integration work in the [next vacuum-module pass](VACUUM_MODULE_NEXT_PASS.md).

The three-section architecture, automatic exchange/charging, vacuum-first
priority, 275 × 275 mm rigid footprint and 180 mm total height remain the design
requirements. Whole-assembly flight stays deferred until ground-module masses
are established. The separate long-reach head remains the solution for the
50 mm sofa clearance.

## Recommended drivetrain

Use two geared brushed motors with integrated encoders, a dual controller with
closed-loop speed control, and compliant purchased tires. This removes the
custom rotor magnet, shaft and commutation development from the main robot.
The drive assemblies should be removable cartridges in each wheeled bottom.

Prices below were checked on 2026-09-12 in USD, before shipping and tax. They are
component prices, not a complete robot or complete assembly order.

| Component | Qty | Recommendation and reason | Unit price |
|---|---:|---|---:|
| Drive motor | 2 | [Pololu #4846, 25D HP 12 V, 75:1, encoder](https://www.pololu.com/product/4846): compact documented gearmotor; 130 RPM nominal no-load speed | $56.95 |
| Wheel | 2 | [goBILDA Hogback 3626-0014-0072](https://www.gobilda.com/hogback-traction-wheel-72mm-diameter-50a-durometer/): 72 mm diameter, 50A silicone tread | $8.99 |
| Wheel hub | 2 | [goBILDA Sonic Hub 1309-0016-0004](https://www.gobilda.com/1309-series-sonic-hub-4mm-bore/): 4 mm clamping bore; nominal mating with the Hogback wheel verified in supplier CAD | $7.99 |
| Dual motor controller | 1 | [RoboClaw 2x7A, current V6B/V6F listing](https://www.pololu.com/product/3682): encoder feedback and velocity control, USB/serial commands | $79.95 |
| **Subtotal** | | Motors, wheels, hubs and controller only | **$227.81** |

Allow approximately $50–100 more for motor plates, caster, suspension hardware,
fasteners and guards at this stage; that allowance is an estimate. Battery,
regulators, protection, wiring, sensors, printed chassis and cleaning hardware
are additional. Stock varies; the Pololu listings allow backorders, so check
delivery before an order. RoboClaw is also listed by
[Basicmicro](https://www.basicmicro.com/motor-controller2).

The [drivetrain sourcing record](DRIVETRAIN_SOURCING.md) adds exact DigiKey,
Mouser and RobotShop cross-references, fulfillment qualifications and conditional
alternatives. It distinguishes manufacturer-shipped Marketplace listings from
distributor inventory; the preferred component choices below remain unchanged.
The wheel-to-hub CAD check now passes: order the two wheels with their two hubs.
Printed bracket integration and final fastening hardware remain unfinished.

The motor's published body is 25 × 69 mm, with a 4 mm D shaft extending 12.5 mm;
reference mass is 104 g. Its gearbox continuous-load recommendation is
4 kgf·cm, approximately 0.392 N·m. This, plus motor heating, governs sizing;
the advertised extrapolated stall torque is not usable continuous torque.
[Motor specifications](https://www.pololu.com/product/4846/specs) and
[load guidance](https://www.pololu.com/product/4846).

For a 72 mm wheel, our proposed 0.15–0.25 m/s cleaning speed needs approximately
40–66 wheel RPM. The nominal unloaded maximum is about 0.49 m/s; commanded
cleaning speed would be limited below that. These are calculated speeds, not
measured cleaning performance.

Use 3–5 kg only as an initial *sizing scenario*, not as the robot's established
mass. For illustration, at 5 kg, assuming rolling resistance coefficient 0.03,
4 N tool drag, 0.2 m/s² acceleration and a 5° station ramp, each 36 mm-radius
wheel needs about 0.19 N·m; a 1.5 multiplier gives about 0.29 N·m. Formula:
`torque = (m*g*Crr + tool_drag + m*a + m*g*sin(ramp)) * radius / 2`.
Actual mop drag, caster swivel resistance and thresholds may dominate this
estimate. Revisit sizing if the load exceeds this scenario; preserve alternate
motor plates. Brushed motors and gearboxes are service parts; this selection
does not establish unattended appliance lifetime.

RoboClaw handles both encoders and motor speed loops. Set motor-specific current
limits, acceleration limits and communication timeout behavior during integration.
Its 7.5 A/channel capability is not an operating-current target for these motors.
Use a separate appropriately rated Pi supply. Account for regenerative braking
in the power design: an ordinary buck converter must not be assumed to absorb
returned energy. The controller is a purchased firmware component; the robot's
CAD, application code and interfaces can still be published openly.
[Controller documentation](https://www.pololu.com/product/3682).

The two purchased B-G431B-ESC1 boards remain with the brushless experiment. They
are not the proposed controller for these two-wire brushed gearmotors.

## Tires, support and wet floors

The wheel manufacturer provides tread material, hardness, mass and CAD, but no
wet wood/tile traction coefficient. I recommend this wheel as a well-defined
candidate, not as a guaranteed wet-floor solution. Its nominal mass is 55 g.
The [manufacturer's STEP model](https://www.gobilda.com/content/step_files/3626-0014-0072.zip)
was inspected in FreeCAD; axial width is approximately 24 mm. The new tires are
therefore substantially wider than the owned 8 mm wheels. Width alone does not
prove better grip on a water/detergent film.

Design each drive cartridge with limited vertical compliance and sufficient
wheel loading. Keep the battery low and make the load distribution work with
both empty and full bins/tanks. Use an accessible, nonmarking soft-tread swivel
caster instead of making the owned metal ball caster the household baseline.
Select its exact part after support height, swept clearance and load are known.
Guard rotating hubs and make hair removal possible without dismantling the core.

For the mop bottom, put the wetted pad behind all normal ground-contact wheels.
Meter water into the pad and lift the pad for repositioning. Prefer forward
passes with dry-route turns; stop water delivery when stopped or reversing.
Lifting the pad does not dry an already wetted route, so plan wet-area crossings
explicitly and use restrained acceleration there. The center of mass and pad
force must still leave useful traction load on the drive wheels.

A brief final-system test on the actual floors remains necessary: dry and freshly
mopped straight travel, starts/stops and turns, with empty/full service loads.
Record slip, stopping distance, scuffing and hair accumulation using the intended
cleaner concentration. This checks application suitability; it does not require
rediscovering undocumented motor torque or constructing an expensive test stand.

## Vacuum and mop hardware

**2026-09-13 reassessment:** the [vacuum review](VACUUM_RECOMMENDATION_REVIEW.md)
prioritizes TriCut investigation and comparison with hair-shedding mechanisms;
the plain Roborock roller is a fallback. Keep the S7/S8 washable-filter candidate
and provisional BIQU WS7040 blower/driver kit. Micronel
below remains a premium comparison; its graph/table discrepancy is documented
in the [earlier selection record](VACUUM_COMPONENT_SELECTION.md).

Use a compact removable head that prevents hair accumulation, accessible end
supports, a sealed collection bin and a replaceable filter with a reproducible
supplier/model. Hair pickup and detangling requirements outrank simpler mechanics.
Design the edge brush to feed the main pickup path. Neither the large owned
filter nor the existing roller-end geometry should force the whole packaging
layout. Approximately 180–200 mm cleaning width is a proposed starting point;
confirm overall cassette width including transmission and bearing supports.

Use a centrifugal suction blower with a published pressure/flow curve and
integrated or explicitly matched electronics. A documented example worth
comparing is the
[Micronel U51DL-012KK-4](https://www.micronel.com/productfinder/radial-blower-u51dl-012kk-4/).
Its [datasheet](https://www.micronel.com/wp-content/uploads/2025/04/U51DL-012KK-4.pdf)
lists a nominal operating point of 180 L/min at 2.5 kPa and 30 W, integrated
control electronics, and 120 g mass. The 4.2 kPa shutoff and 440 L/min free-flow
figures are different endpoints, not simultaneous performance. This is a
filtered-air candidate downstream of the bin/filter, not a debris-handling fan.

This is **a blower shortlist entry, not an instruction to buy**: the
[Micronel USA DigiKey marketplace listing](https://www.digikey.com/en/products/detail/micronel-usa/U51DL-012KK-4/14545084)
was $398 plus separate shipping. Compare that cost with other documented
blower/controller assemblies after estimating the head/filter pressure losses.
The linked sheet also lists static speed above its continuous speed limit;
resolve that operating restriction before release. Do not size from shutoff
pressure, assume blocked operation is acceptable, or substitute the externally
commutated `-5` model as if it were the same electrical assembly.

For the later dedicated mop bottom, start with a replaceable microfiber pad,
metering pump, shutoff provision and pad lift. Preserve automatic station
servicing. Pad washing/drying, water delivery and drag need an integrated layout;
individual pump or actuator SKUs are not yet selected.

## Core and power

The Pi 4 and RPLIDAR A1 remain reasonable starting components because their
interfaces and geometry are documented. Retaining them does not require proving
the unknown BDUAV motor specifications. Keep a local microcontroller for physical
bump/cliff inputs, module latches and tool interlocks; reserve near-floor obstacle
sensing in addition to the planar LiDAR. LLM/MCP planning must not run the wheel
commutation or immediate stop loop.

Do not freeze a new battery around either the owned 3S pack or the deferred
flight module. Select a protected rechargeable pack, matching dock charger,
temperature monitoring and power distribution together after the operating
loads are budgeted. A 4S architecture remains possible, but a fully charged 4S
pack is 16.8 V: neither a nominally 12 V motor nor the shortlisted blower should
be assumed to accept that as an unrestricted supply. The blower's stated range
is 9–15 V. Specify motor voltage/current management and a regeneration path as
part of the power design, before choosing a battery SKU.

## Placement work that follows

The current ground CAD, JSON and component CSV still describe the earlier
inventory-based placement. They do **not** establish fit for this recommendation.
Keep them as a reference while preparing the next revision:

1. Repack the wider wheel cartridges, caster, compact head and air path inside
   275 × 275 × 180 mm, including suspension motion and caster sweep.
2. Carry forward the verified wheel-to-hub mating geometry, and finish D-shaft
   clamping engagement, screw lengths, bearing loads, encoder clearance and tool
   access. Include the tire's inward overhang in the bracket design.
3. Reserve bin/tank and dock interfaces; calculate empty/full wheel loading and
   mass allowances for all three sections.
4. Complete power/control wiring and produce one compatible, costed assembly
   list before further fit prints or purchases.

No additional owner measurements are needed to begin that placement pass.

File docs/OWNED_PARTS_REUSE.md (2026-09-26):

# Owned parts: first ground build

2026-09-05. Use the owner's inventory to replace earlier shopping references.
The working combination is **Pi 4 + RPLIDAR A1 + 60 mm wheel reference** and the CBM blower.
The two owned GA25-371N 12 V / 18 RPM encoder motors are available for a slow
prototype. The owner wants faster long-term alternatives; the
[motor comparison](DRIVE_MOTOR_OPTIONS.md) recommends Pololu 25D HP encoder
motors as the leading candidate. No brushed H-bridge or standalone MCU is on hand.
Update 2026-09-06: **two B-G431B-ESC1 controllers are purchased and awaiting
delivery** for the separate BDUAV rolling rig; each includes an MCU and ST-LINK.
The owner explicitly permits different parts when installed size, mass or performance
warrants them. Reuse is a starting preference; it does not fix component choices.
This is a reuse assessment, not a released wiring diagram or purchase list.

[owned_parts.json](../config/owned_parts.json) records ownership, assignments,
unknown variants and resolved questions. Stock counts remain unknown except
where explicitly reported; measured masses are still unknown. [ground_components.csv](../config/ground_components.csv)
lists parts needed for each assembly; its quantities are requirements, not a count
of available stock. Alternative Pis and station boards are not all installed on
the robot or added to its carried mass.

## Assignments

| Owned item | Proposed use | What remains to establish |
|---|---|---|
| SLAMTEC RPLIDAR A1 | First core-mounted floor-navigation scanner; replaces the C1 shopping reference | Exact A1 revision, supplied interface/cable and mount geometry |
| Raspberry Pi 4 | First navigation computer in a removable core tray | RAM, storage/cooling and performance with the actual navigation workload |
| Raspberry Pi 5 | Interchangeable compute alternative if vision/planning needs it | Recheck cooling, connector access and supply capacity when substituted |
| Raspberry Pi Zero 2 W | Candidate station communications/job interface | Local station motion/retention still needs independent control; no reason to carry all three Pis |
| Pololu 90 × 10 mm wheels | Larger alternative; replaced by 60 mm reference in compact layout | Exact hub variant, matching adapters and available quantity |
| Unidentified 60 × 8 mm wheels | Current reference; 3 mm center hole and no hub protrusion owner-confirmed | Exact hole/recess profile, face-hole spacing, selected adapter, tire, quantity and mass |
| Pictured passive ball casters | Owner reports 28 × 45 mm plate, 13 mm overall height, 3 mm mount height; reserve candidate | Exceeds current 20 mm support bay; mounting datum, load, quantity and floor behavior unresolved |
| GA25-371 motors, originally reported as GA25-371N | Two owned: 12 V, 18 RPM, encoders, D shafts; optional slow prototype or reserve | Faster long-term alternatives in the motor comparison; owned shaft, mounting, encoder and current details remain unknown |
| CBM-979533B-168 | Initial filtered, roller-assisted vacuum blower | Actual pickup with the chosen duct/filter, startup load and supply conditioning |
| Vacuum consumables, initial link Amazon B088W8HS1Y | Owner reports s9/s9+ parts; complementary styles in 254 × 28 mm and 184.15 × 28 mm sets; filter body 136 × 76 × 14 mm | End geometry and filter tab placement; drive hardware still to select; see [vacuum head](VACUUM_HEAD.md) |
| PCA9685 board | Servo signal generation for station handling or a later cleaning actuator | Board voltage ratings, actuator power supply and enable behavior |
| Waveshare Servo Driver HAT | Alternative to the loose PCA9685 board for a compatible servo task | Exact HAT revision, its regulator limits and any shared Pi power connections |
| BDUAV 2204-260KV motors | Physical label and direct M2 rotor-to-wheel attachment confirmed; drive candidate | Conflicting purchase-page sheet; actual ratings/mass, sustained torque, feedback and wheel-bearing loads |
| Four iFlight 2750 KV motors | Reserve inventory; XING-E Pro 2207 working family identification | Exact physical model/revision, mass, condition and application-specific torque/thermal performance; not selected for the rolling rig |
| Two ST B-G431B-ESC1 controllers, purchased but not received | Selected for the BDUAV rolling rig; one MCU and power stage per wheel | External encoder fitting, custom firmware, low-current calibration and actual drive results; see [preparation](../design/experiments/drive_rig/PREPARATION.md) |

The HAT and loose PWM board overlap in function. Allocate one where needed instead
of installing both by default. A Linux Pi and a PWM expander do not by themselves
provide encoder feedback loops, brushed-motor power switching or a command-loss
watchdog. The purchased ST boards cover the rolling rig's MCU and brushless power
stages; its feedback and shutdown firmware still needs implementation. A brushed
gearmotor bottom would need its own compatible driver and controller.

## Changes to core packaging and power

Start with the Pi 4, with separate battery and compute trays and room to change
the computer carrier. Raspberry Pi recommends a 5 V/3 A supply for Pi 4 and a
5 V/5 A supply for Pi 5; a Pi 5 on 3 A limits USB peripheral current to 600 mA.
These are supply requirements, not constant operating consumption. Account for
peripherals and cooling separately. [Raspberry Pi power documentation](https://www.raspberrypi.com/documentation/computers/raspberry-pi.html#power-supply)

The A1M8 reference is approximately 96.8 × 70.3 × 55 mm and 170 g, larger than the
earlier C1 reference. Mount to the core with a clear scan plane and a cap opening
that permits top removal without unplugging the scanner. Its single scan plane
does not replace floor cliff sensors, bumpers or detection of objects below/above
that plane. [SLAMTEC family dimensions](https://www.slamtec.com/cn/lidar/a1spec)

Use the actual revision's electrical specification. The A1M8 v3.0 datasheet lists
300 mA typical scanner working current, 500 mA typical/600 mA maximum scanner
startup current, and about 100 mA typical motor current at 5 V. Do not budget the
whole spinning scanner as the product summary's 100 mA. Preserve scanner/motor
power separation or use the appropriate development adapter. [A1M8 datasheet, pp. 10–12](https://wiki.slamtec.com/download/attachments/83066883/LD108_SLAMTEC_rplidar_datasheet_A1M8_v3.0_en.pdf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)

The original Waveshare HAT manual specifies 6–12 V input and up to 3 A from its
5 V regulator. A fully charged 3S LiPo is 12.6 V, beyond that stated input range.
Until the exact board revision is identified, do not connect it directly to the
pack or count its regulator as the combined Pi/servo supply. [Waveshare manual](https://files.waveshare.com/upload/1/1b/Servo_Driver_HAT_User_Manual_EN.pdf)

## Wheel and motor fit

The standard Pololu 90 × 10 mm D-shaft wheel has a **3 mm bore** and mounting holes
for universal hubs; a servo-spline version also exists. If the owned motor shaft
is larger, choose a matching bolt-on hub rather than forcing the wheel onto it.
Check the owner's exact wheel version. [Pololu wheel and hub compatibility](https://www.pololu.com/product/1435)

At 90 mm diameter, wheel travel is `pi × 0.09 = 0.2827 m/revolution`.
The owner has two matching **12 V / 18 RPM encoder motors with D shafts**. At the
listed speed, travel is `pi × 0.09 × 18 / 60 = 0.0848 m/s` (about 8.5 cm/s).
Actual loaded speed is unmeasured; the listing does not establish whether 18 RPM
is a no-load or rated-load value. This is below the proposed 0.15–0.25 m/s cleaning
range. The owner has now asked for faster long-term alternatives: use the
[documented motor comparison](DRIVE_MOTOR_OPTIONS.md) for that selection and
keep this pair available for prototype work. Changeable motor plates preserve
both options; the whole GA25 family is not ruled out by this variant's speed.

The provided listing says GA25-371; the earlier message said GA25-371N. No reliable
exact manufacturer specification was found. Record voltage, RPM and encoders as
owner-supplied specifications; leave shaft diameter, gearing ratio, current ratings,
encoder voltage/counts, dimensions and mass unknown. Do not infer torque from the
low speed or copy figures from a similarly named motor.

Use replaceable motor plates and allow room for hubs, encoder wiring and axle hair
shields. Both wheel choices keep the main chassis outside the sofa gap. The compact layout
uses owner-reported 60 × 8 mm wheels; hub and support geometry must be confirmed
before releasing motor plates.

### Owned 60 mm wheels: current compact reference

The owner reports **60 mm diameter and 8 mm width**; no model number is known.
Do not assume Pololu construction, a 3 mm D bore or the same tread as the 90 mm
wheels. The owner now confirms a **3 mm center hole and no hub protrusion**, plus
face holes that work with the BDUAV motor. Exact hole/recess profile, bolt spacing
and the chosen gearmotor adapter remain to establish. The owner now confirms
that the BDUAV matching face rotates and accepts the wheel directly with M2 bolts;
this option needs no separate wheel hub. With wheel centers unchanged, reducing the
former 10 mm allowance to 8 mm adds 1 mm clearance at each face of each tire.
The wheel remains 8 mm wide; a separate motor adapter can add installed width.
Its offset and tire load rating remain unqualified.

| Wheel diameter | Travel per revolution | Calculated speed at 18 RPM |
|---|---:|---:|
| 90 mm | 0.283 m | 0.0848 m/s (8.5 cm/s) |
| 60 mm | 0.188 m | 0.0565 m/s (5.7 cm/s) |

These are geometric comparisons at equal wheel RPM, not loaded measurements.
The 60 mm wheel has two-thirds the travel per revolution and, ideally, 1.5 times
the tangential force at equal axle torque (`F = torque / radius`). Actual grip,
motor loading and floor performance still depend on the complete drivetrain.
Its smaller envelope may help packaging, but chassis height and ground clearance
also depend on where the axles are mounted.

Use the 60 × 8 mm pair for the 275 mm compact layout. Retain the 90 mm pair as an
alternative. The Pololu
75:1 #4846 motor is the current replacement reference for the smaller wheels;
loaded speed, torque and hub fit remain to qualify. Count only the installed set
in each bottom's mass; no wheel purchase is proposed.

## Pictured passive ball casters

Owner photographs dated 2026-09-06 show an exposed metallic-looking ball in a
pale housing, a two-hole flange and black backing. This identifies the general
ball-caster form, not its manufacturer, alloy or load rating. The owner now
reports a **28 × 45 mm mounting plate, 13 mm overall height and 3 mm mount
height**. Record the 3 mm as a provisional flange-thickness interpretation within
the 13 mm overall envelope, not an additional 3 mm or a floor-contact datum.
The plate exceeds the current 20 × 20 mm reservation in either axial orientation;
13 mm overall height fits its vertical allowance. A revised mount/placement is
needed before using it. This does not mean it cannot fit elsewhere in the robot.

Ball casters can provide the third contact point of a differential-drive robot
and roll in arbitrary horizontal directions. Pololu describes this application
for its own small-robot casters; its ratings do not apply to these unidentified
parts. [Manufacturer category reference](https://www.pololu.com/category/45/pololu-ball-casters)

For this home's wood/tile and dog hair, the design preference is a small swivel
caster with a soft, non-marking tread, shielded axle and easy removal for cleaning.
Blickle documents floor-preserving, non-marking rubber and polyurethane tread
options; this supports a material preference, not a guarantee that any particular
caster fits or will leave the owner's finish untouched.
[Tread material guide](https://www.blickle.us/en-us/guide/material-description-wheel-treads)

The exposed ball's concentrated contact and possible grit/hair ingress are
engineering concerns, not observed failures of the owned part. A soft-tread
caster also needs hair clearance and loaded rolling checks. Keep the pictured
parts as candidates for controlled bench supports or station guide mechanisms,
subject to mounting orientation and load qualification. No station load capacity
is inferred, and the casters are not added to the current carried mass.

## Component replacement priorities

The owner's explicit direction is to consider replacements for parts that are too
heavy, large or underpowered. Compare complete installed assemblies, including
mounts, regulators, wiring and cleaning performance; catalog dimensions alone
can shift bulk into another subsystem. Preserve the 275 × 275 × 180 mm ground
constraints while evaluating alternatives. Propulsion remains deferred.

| Component | Current assessment | Replacement comparison before final detail |
|---|---|---|
| 60 × 8 mm drive wheels | Useful compact reference; no dimensional reason to discard them | Hub compatibility, tire grip and floor behavior; loaded speed/torque still govern motor choice |
| Passive support | Owned 28 × 45 mm flange exceeds the current 20 mm reservation; 13 mm height is compact | Soft-tread swivel caster with published dimensions/load, hair access and suitable installed height; revise support placement if needed |
| CBM blower and filter arrangement | Reuse candidate; upright placement requires core openings and limits bin/electronics space | High priority: compare a compact vacuum blower with a published pressure-flow curve, matched filter and complete installed power/mass; dog-hair pickup determines adequacy |
| Roller drive and controls | Unselected; tight reserved bays | Fit a serviceable drive, couplers and power stages before releasing the cassette or electronics carriers |

Keep the owned Pi 4, A1 and 3S pack as current references. If alternatives improve
the complete system, document the benefit and consolidated compatible cost before
proposing purchases. No new component or purchase is selected by this update.

### Owner replies recorded

Recorded: wheel center hole 3 mm, no hub protrusion, direct M2 fastening to the
rotating BDUAV face; caster plate 28 × 45 mm, overall height 13 mm, mount height
3 mm. Exact wheel recess/bolt geometry and screw engagement remain later fit details.

The physical motor is confirmed to be marked **BDUAV 2204-260KV**. The newly
attached **ML2206B / 160 RPM/V** sheet came from its purchase page and conflicts
with that label. Retain the image's claims as disputed evidence, without assigning
its 1.3 A, 15 W, 5.6 ohm, 23 g or 28 × 15 mm values to the owned motor.
The [drive assessment](DRIVE_MOTOR_OPTIONS.md#owned-bduav-2204-260kv-as-a-wheel-drive-alternative)
contains the transcription and implications. Both latest questions are resolved
and saved in the inventory; no additional owner question is pending.

## CBM blower integration

The manufacturer's CBM-97B rev. 1.05 datasheet identifies this as a two-wire,
12 V blower, 97 × 95 × 33 mm, with a 184 g reference mass. Its model-specific
range is 6–12.6 V. It lists 54.7 CFM at zero pressure and 5.22 in H2O
(approximately 1.30 kPa) at zero flow; those endpoints are not simultaneous.
[Manufacturer datasheet, pp. 1, 4–5](https://www.sameskydevices.com/product/resource/cbm-97b.pdf)

Use it after the bin/filter with wide passages and a replaceable mount. The modest
pressure budget makes filter loading important; installed dog-hair pickup remains
to demonstrate. Keep the long-hose low-clearance bottom a separate evaluation.

The datasheet explicitly disallows power/ground PWM for speed control. Use a
suitable DC supply with protected on/off switching; no aircraft ESC is required.
It lists 3.85 A and 48.30 W at 12 V, which disagree arithmetically. Retain that
conflict and establish startup/current demand before selecting protection.
The model is discontinued but usable inventory. [Same datasheet, pp. 1, 6](https://www.sameskydevices.com/product/resource/cbm-97b.pdf)

The pack's 3S voltage range overlaps the blower's, but reaching its 6 V minimum
is not an acceptable battery discharge rule. Battery protection and switching
transients still govern a direct-pack branch; a regulated branch is another option.

## Rolling experiment motors: BDUAV 2204-260KV

Direct M2 attachment to the rotating motor face is now owner-confirmed. That
eliminates a separate wheel hub for this option and makes it worth retaining as
a compact drive candidate. The physical 2204-260KV label conflicts with the
purchase-page ML2206B/160KV image, so the latter's ratings and mass remain disputed.

The 60 mm wheels need about 48–80 RPM for the proposed cleaning speed. A complete
BDUAV drive would need matched three-phase drivers, rotor feedback and local
control, plus qualified torque, thermal behavior and wheel-bearing support. The
[detailed assessment](DRIVE_MOTOR_OPTIONS.md#owned-bduav-2204-260kv-as-a-wheel-drive-alternative)
keeps the encoder gearmotor as the current layout reference while those performance
details are unresolved. BDUAV hardware is not added to the installed BOM or carried
mass; no numerical weight saving is established from the conflicting image. The
owner has now requested a [rolling drive rig](../design/experiments/drive_rig/README.md)
to measure travel time versus carried weight. Its printed fit design reuses the
motors, 60 mm wheels, caster, Pi and 3S battery; proposed controllers and feedback
are listed in one consolidated hardware allowance. This is separate from the
installed cleaning-bottom BOM and does not restart EDF testing.

For that rig the owner measured **28 mm motor diameter, 13 mm thickness, four M2
stationary holes on an 8 mm square, about 4 mm depth to an obstruction and a
rotating 4 mm center bore**. Caster hole pitch is **34 mm**, with **3.5 mm holes**.
These measurements supersede the earlier missing geometry. Motor torque/current
ratings and actual assembly masses remain unmeasured.

## Additional iFlight motors: reserve inventory

On 2026-09-06 the owner reports **four matching 2750 KV motors**, linked through
[Amazon B0G4VFNTRS](https://www.amazon.com/iFlight-1800KV-Brushless-Racing-Quadcopter/dp/B0G4VFNTRS).
The URL's 1800KV text is superseded by that answer. Direct Amazon retrieval failed;
use XING-E Pro 2207 as the working family identification and confirm the complete
physical model/revision before applying its specifications to a powered design.
The [official iFlight family page](https://iflight-rc.eu/en/products/xing-e-pro-2207-fpv-motor)
lists 1800/2450/2750 KV variants, 33.8 g including wires, diameter 28.5 mm and
overall length 33.1 mm, a 5 mm shaft and M3 mounting on a 16 mm square. These are
manufacturer references, not owned-part measurements. The mounting and shaft
arrangement differ from the BDUAV's M2/8 mm pattern and direct wheel attachment.

For scale, `2750 * 11.1 = 30,525 RPM` is an approximate unloaded speed at nominal
3S voltage. A 60 mm wheel needs `0.2 * 60 / (pi * 0.06) = 63.7 RPM` at the proposed
0.2 m/s cleaning speed. This comparison does not establish minimum controllable
speed or prescribe a gearbox ratio. A direct drive with rotor feedback and
current control is possible in principle, but its loaded starts, continuous
torque, heat and bearings need qualification. Propeller peak-power figures do not
establish continuous wheel-duty output; continuous torque depends on current and
heat dissipation. [Motor operating-range explanation](https://support.maxongroup.com/hc/en-us/articles/360000350014-Continuous-operation-range-of-BLDC-EC-Motors)

An engineered reduction drive is another option, with additional gearing,
supports, hubs and enclosure work. Neither path simplifies the existing BDUAV
fit experiment. Retain the current rig and keep these four motors in reserve.
They are candidates to revisit for propulsion after the full carried mass is
known; this is not a lift selection or a restart of the deferred EDF experiment.

**Inventory question resolved:** What model/KV and how many? Owner answers
"I have 4 motors, 2750 family." Quantity and KV are recorded; the full physical
model/revision remains a later integration detail.

## Local control and remaining inventory

The PCA9685 generates PWM signals; its outputs are milliamp-level, not wheel-motor
power stages. It has a shared PWM frequency across channels. Use an appropriate
H-bridge for each brushed drive motor and a local controller for encoders, stopping
and communication-loss handling. For servo tasks, provide suitable servo power
and a hardware enable/disable path; a stopped host must not leave unsafe commands
running indefinitely. [NXP PCA9685 documentation](https://www.nxp.com/docs/en/data-sheet/PCA9685.pdf)

```mermaid
flowchart LR
    L["Owned RPLIDAR A1"] --> P["Owned Pi 4: navigation"]
    P --> C["Local controller(s): purchase required"]
    C --> H["Dual brushed-motor driver: purchase required"]
    H --> M["Brushed encoder pair: owned prototype or faster candidate"]
    M -. "encoder feedback through appropriate voltage interface" .-> C
    C --> S["Protected DC on/off branch"]
    S --> B["Owned CBM blower"]
```

Two references for the missing electronics are:

| Needed function | Candidate for the consolidated BOM | Qualification still required |
|---|---|---|
| Two brushed-motor power channels | Cytron MDD10A Rev. 2.0; 5–30 V, 10 A continuous/channel, 3.3 V-compatible PWM/direction, 84.5 × 62 mm PCB; manufacturer lists $25.90 before delivery/tax on 2026-09-05 | Motor startup/stall current, protection, braking energy and connector/height allowance. Its current rating is not a gearbox-protection setting. [Cytron specifications](https://www.cytron.io/cytron/p-10amp-5v-30v-dc-motor-driver-2-channels) |
| Local encoder loops and watchdog | Espressif ESP32-DevKitC V4 as the controller reference | Encoder signal levels and chosen pins; power/USB arrangement; separate transceivers and termination if retaining CAN across the module interface. [Board guide](https://documentation.espressif.com/esp-dev-kits/en/latest/esp32/esp32-devkitc/user_guide.html) |

The first driving prototype needs a bottom controller and dual motor driver. The
core's separate power/interlock controller and eventual station controllers remain
separate BOM entries; one development board does not cover the completed system.
These are layout candidates, not an instruction to order an incomplete electronics
kit now. Keep power regulation, protection, cables, encoder interfaces and sensors
in the same consolidated BOM.

**Owner answers recorded:**

- Motor listing: GA25-371, 12 V, 18 RPM, encoder, D shaft.
- Matching motors available: **two**. The listing's “1Pcs” was not the total stock.
- Brushed DC motor drivers and microcontroller boards available: **none**.

**Cleaning-head inventory answer, 2026-09-06:** The owner confirms s9/s9+ parts,
with two roller styles in each of two lengths: 10 inches (254 mm) and 7.25 inches
(184.15 mm). The filter body is 136 × 76 × 14 mm, with a 20 × 6.5 mm pull tab
raised roughly 5 mm and centered along the width axis on one side. Tab placement
and mating details remain to establish; a complete powered head is not reported.
Use the short pair as the current everyday-layout reference to meet the 275 mm
body constraint; the long pair is an oversized-layout alternative. The [vacuum-head record](VACUUM_HEAD.md) and inventory preserve
these answers. The owner subsequently confirms **28 mm diameter for both styles**;
use that for both length sets. The initial envelope questions are resolved, and
the first dimensioned clearance study is linked from the vacuum-head record.

Verify shafts/mounts and encoder pinout before releasing the motor mounts and wiring, then place the core
and vacuum hardware in the dimensioned layout. HAT revision and scanner cable
remain open details for their own wiring. No replacement LiDAR, Pi, drive wheels
or blower is proposed. Faster wheel motors are recommendations, not selected or
ordered parts; see the motor comparison for speed, torque, fit and costs.

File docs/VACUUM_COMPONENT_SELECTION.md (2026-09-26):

# Everyday vacuum: consumables and blower selection

**Consumable recommendation superseded:** the
[requirements-based review](VACUUM_RECOMMENDATION_REVIEW.md) now prioritizes
TriCut investigation against hair-shedding alternatives, retaining an S7/S8-family
washable-filter candidate. The BIQU blower remains
provisional. The dual iRobot roller/s-series filter selection and associated
packaging and shopping figures below describe the earlier 2026-09-13 pass.
Its blower sources and curve calculations remain useful; they do not establish
the new filter's resistance. Drivetrain purchases are unchanged. Flight remains
deferred.

The [selection record](../config/vacuum_selection.json) separates SKU information,
owner measurements, proposed allowances, sourcing and unresolved items. It does
not relabel unidentified inventory as genuine iRobot parts.

### Basis for retaining the owned consumables
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

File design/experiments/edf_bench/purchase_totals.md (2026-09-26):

# EDF purchasing allowances

**Deferred proposal; not a current purchase budget.** The owner rejected this
cost for initial fan selection. See the [published-data comparison](../../../docs/PROPULSION_COMPARISON.md).

Generated from [hardware.csv](hardware.csv). USD, before shipping/tax, prepared 2026-09-05.

Only the pivot and TST-20 lines use checked published prices. Other lines are planning allowances; supplier stock and pack pricing can change.
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

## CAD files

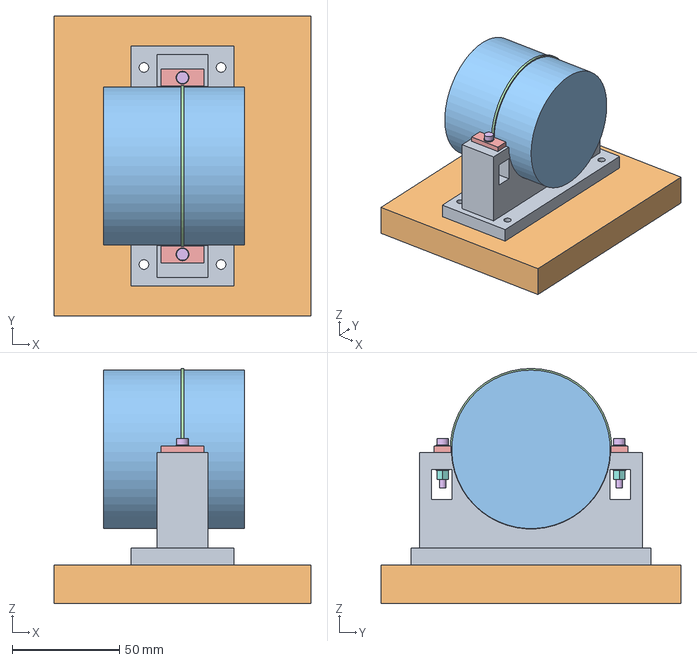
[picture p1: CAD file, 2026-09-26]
design/experiments/edf_bench/output/retaining_mount_assembly_v2.step
120.0 x 140.0 x 109.8 mm

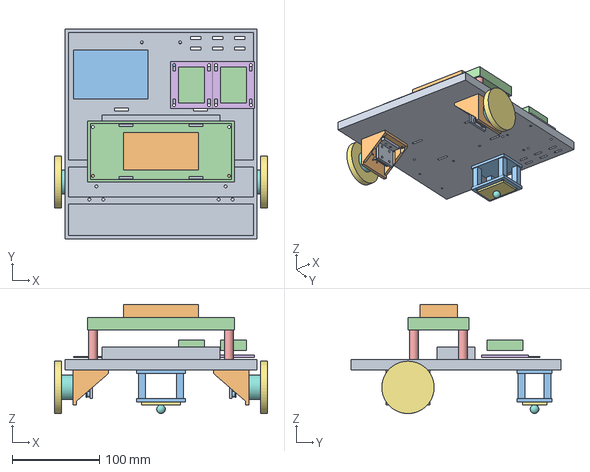
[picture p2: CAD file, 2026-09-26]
design/experiments/drive_rig/output/drive_rig_assembly.step
244.0 x 240.0 x 125.0 mm

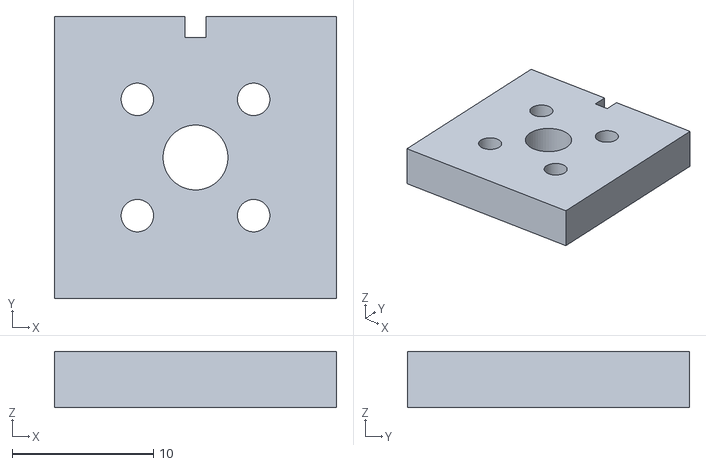
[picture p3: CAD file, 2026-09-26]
design/experiments/drive_rig/output/motor_mount_coupon_8p25mm.stl
20.0 x 20.0 x 4.00

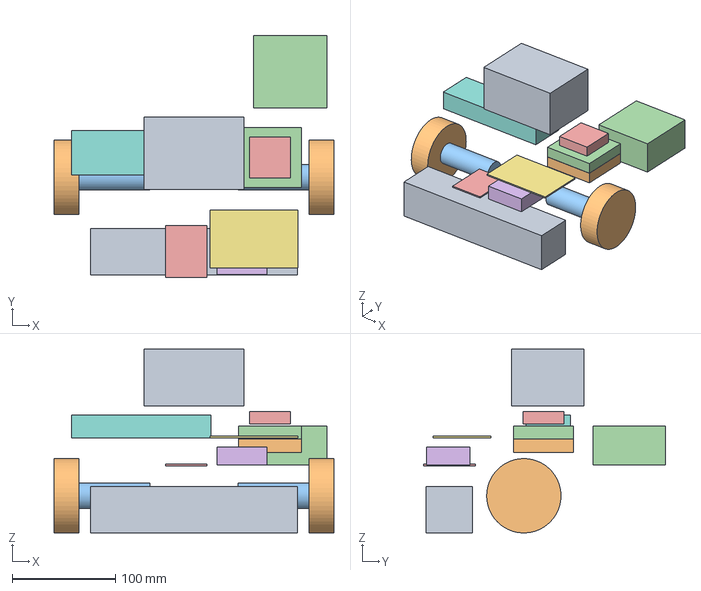
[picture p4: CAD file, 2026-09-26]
design/ground/output/vacuum_integration.step
271.0 x 234.0 x 178.0 mm

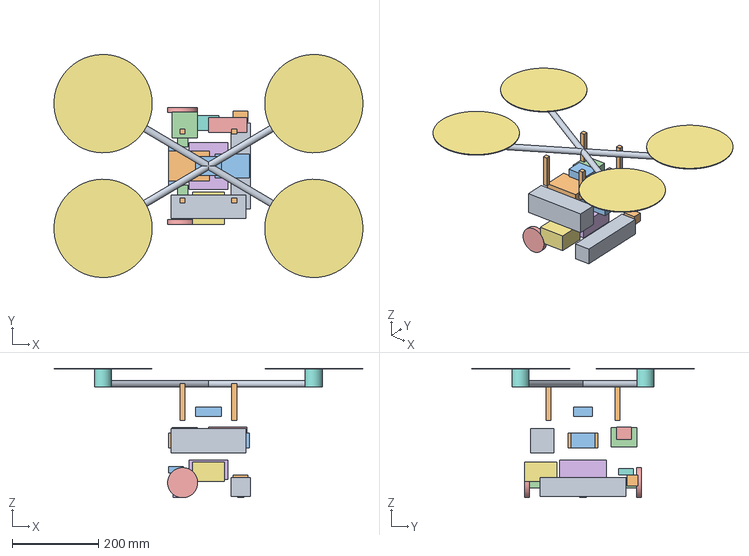
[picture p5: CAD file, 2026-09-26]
design/output/robot_concept.step
718.4 x 518.5 x 301.0 mm

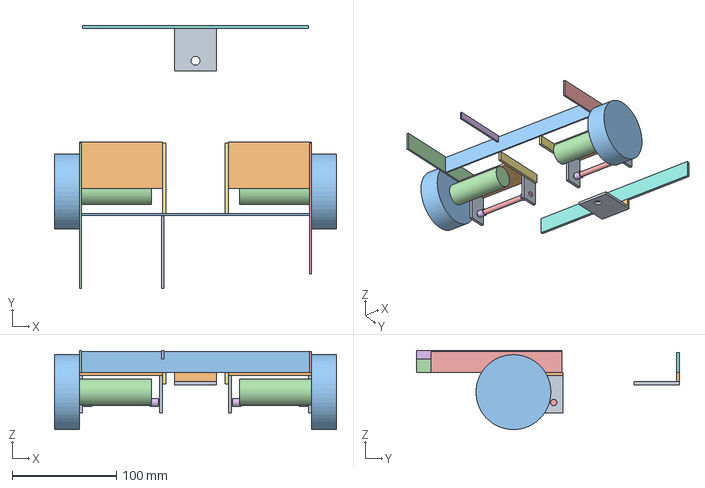
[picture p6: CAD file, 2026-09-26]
design/system/output/floor_support_bump.step
271.0 x 253.0 x 75.9 mm

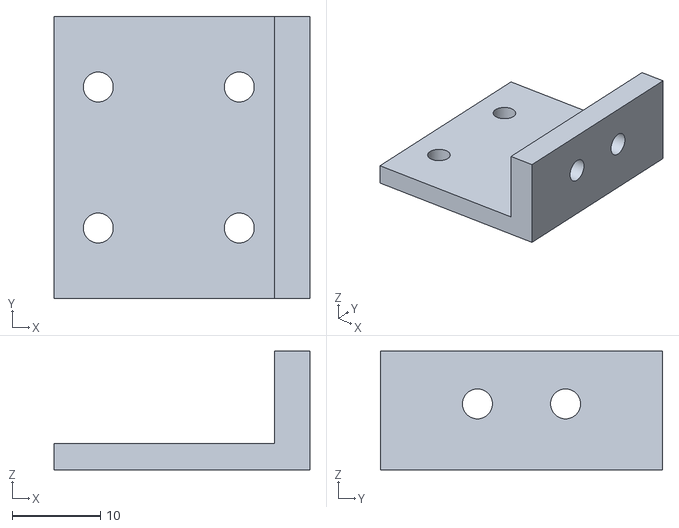
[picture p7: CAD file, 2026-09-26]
design/experiments/drive_rig/output/encoder_carrier.stl
29.0 x 32.0 x 13.5

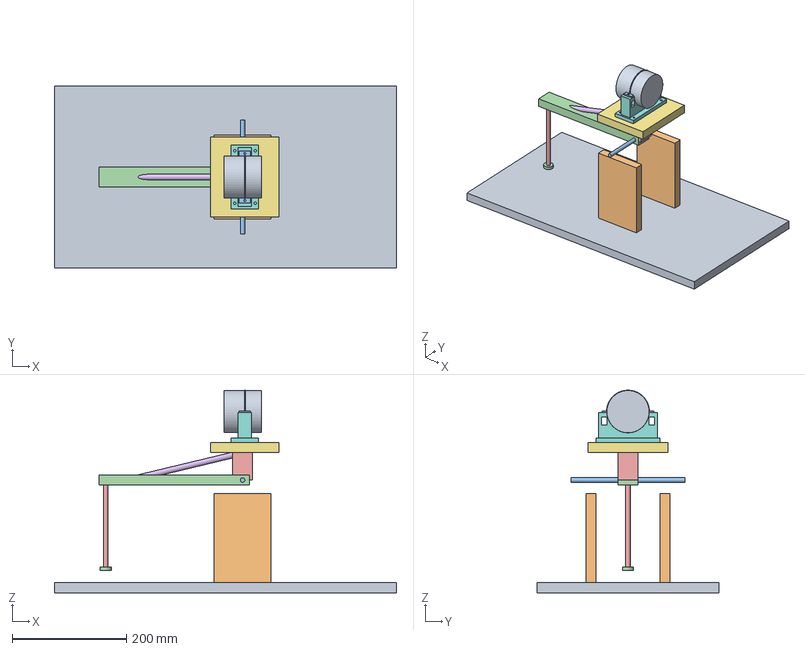
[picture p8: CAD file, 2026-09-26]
design/experiments/edf_bench/output/bench_layout.step
600.0 x 320.0 x 355.8 mm

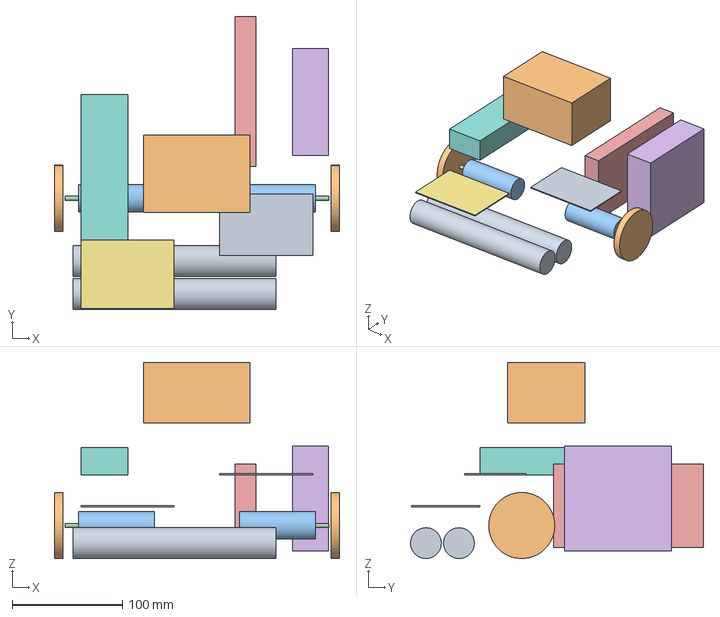
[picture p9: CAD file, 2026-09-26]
design/ground/output/ground_placement.step
259.0 x 266.0 x 178.0 mm

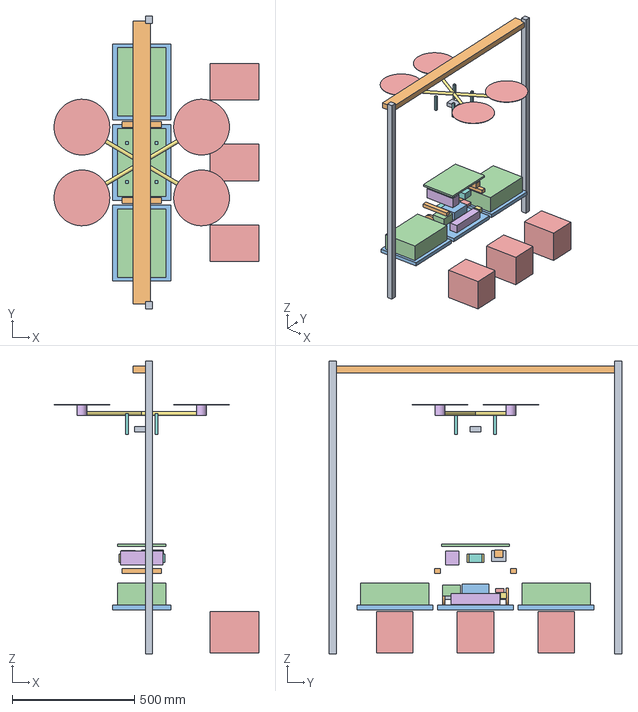
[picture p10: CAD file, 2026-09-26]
design/output/station_concept.step
839.1 x 1200.0 x 1200.0 mm

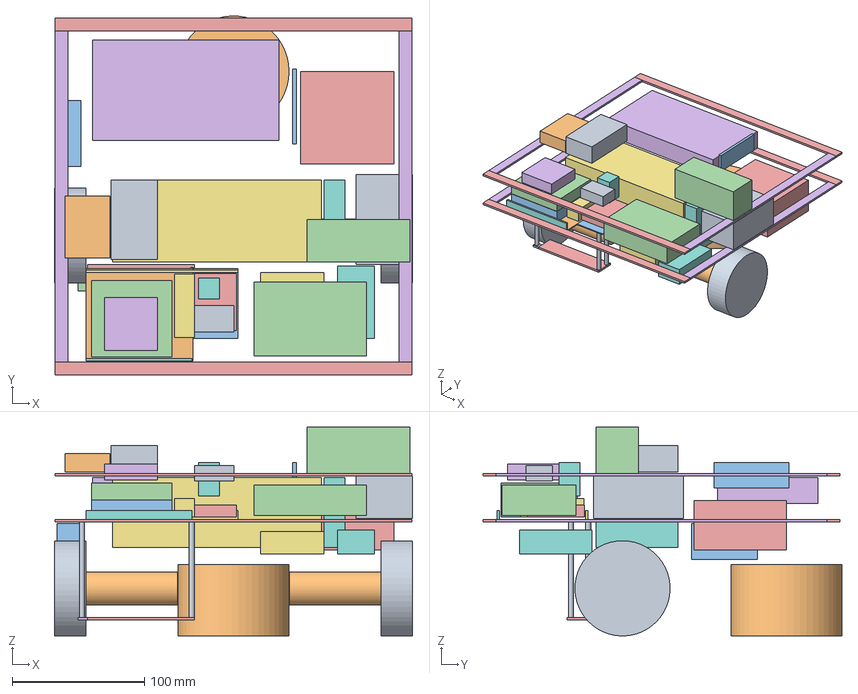
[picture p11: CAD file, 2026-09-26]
design/system/output/core_partition.step
271.0 x 271.5 x 158.0 mm

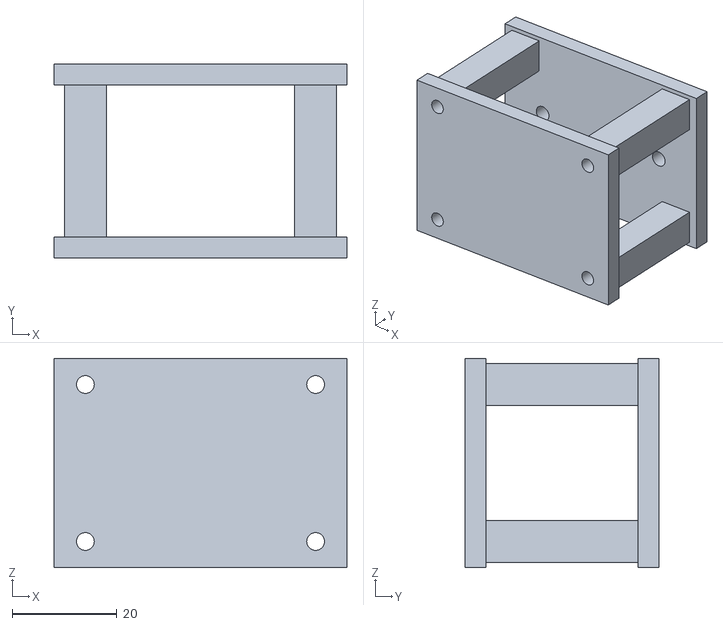
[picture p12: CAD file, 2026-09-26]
design/experiments/drive_rig/output/caster_riser.stl
56.0 x 37.0 x 40.0

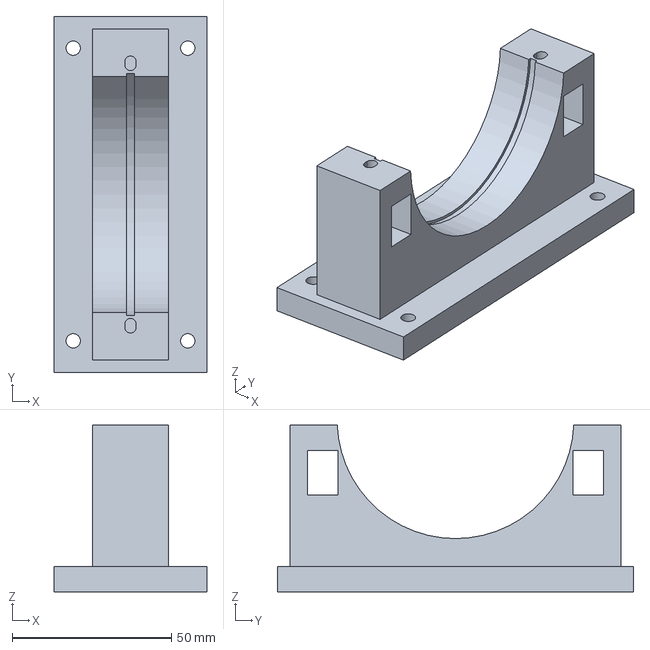
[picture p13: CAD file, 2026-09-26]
design/experiments/edf_bench/output/retaining_cradle_v2.step
48.0 x 112.0 x 52.5 mm

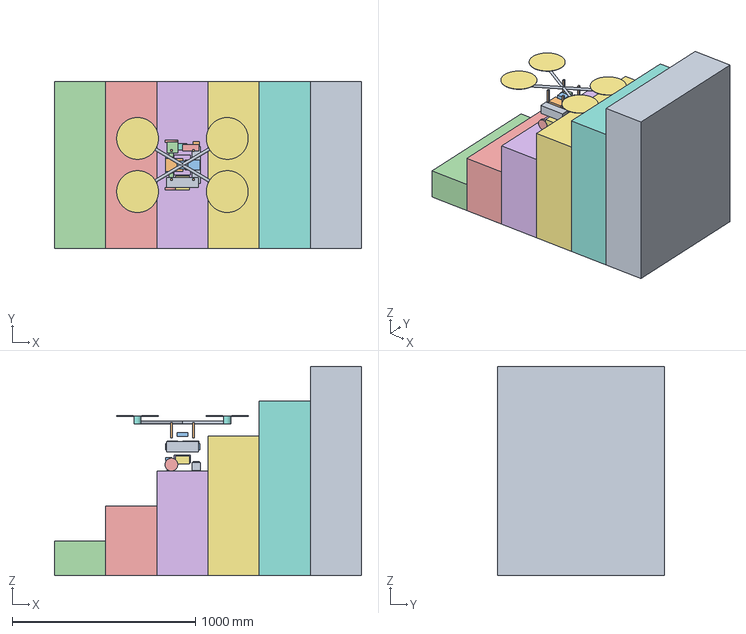
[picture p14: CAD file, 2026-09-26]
design/output/stair_concept.step
1676.4 x 914.4 x 1143.0 mm

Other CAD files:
design/system/output/floating_heads_mop_working.step
design/experiments/drive_rig/output/magnet_stem_fit_gauges.stl
design/experiments/edf_bench/output/unpowered_fit_gauge.step
design/system/output/frame_joints_duster.step
archive/ground-placement-380x400/output/ground_placement.FCStd
archive/ground-placement-380x400/output/ground_placement.step
design/experiments/drive_rig/output/ballast_tray.stl
design/experiments/drive_rig/output/deck.stl
design/experiments/drive_rig/output/drive_rig_assembly.FCStd
design/experiments/drive_rig/output/electronics_carrier.stl
design/experiments/drive_rig/output/magnet_carrier.stl
design/experiments/drive_rig/output/magnet_carrier_4x2mm.stl
design/experiments/drive_rig/output/magnet_carrier_4x2mm_stem_3p4mm.stl
design/experiments/drive_rig/output/magnet_carrier_4x2mm_stem_3p4mm_plus2p5mm.stl
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

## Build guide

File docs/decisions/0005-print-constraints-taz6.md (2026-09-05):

# 0005. Design rules for the LulzBot TAZ 6

**Status:** Accepted
**Date:** 2026-08-22

## Context

All structural parts are printed on a LulzBot TAZ 6. Its capabilities and limits are a
hard input to the mechanical design, not an afterthought — particularly the stock 0.5 mm
nozzle, which is coarser than most current hobby printers.

## Decision

Adopt these as binding design rules for every printed part in the project.

| Rule | Value | Reason |
|---|---|---|
| Max single part | 250 × 250 × 230 mm | 280 × 280 × 250 volume, with margin |
| Base outer diameter | ≤ 250 mm | Single-piece printable |
| Min wall | 1.5 mm (3 × 0.5 mm) | Nozzle width |
| Min feature | 2.0 mm | Below this the nozzle won't resolve it |
| Layer height | 0.25 mm typical | |
| Default material | PETG | |
| Fasteners | M3 heat-set inserts | Never self-tap into printed plastic on a load path |
| Precision surfaces | **Steel hardware only** | See below |

## The 0.5 mm nozzle rule

**No printed plastic surface is a precision surface.** Anything that needs to locate,
repeat, or wear must be steel:

- Kinematic coupling: Ø8 mm bearing balls into Ø3 mm dowel-pin vees. The plastic only
  holds the steel in roughly the right place.
- Latch detent: Ø6 mm bearing balls.
- Rotating joints: real bearings, not printed bores.
- Threads: heat-set inserts, not printed threads.

This is good practice on any printer. On a 0.5 mm nozzle it is mandatory — a printed vee
groove would have visible layer stepping across exactly the surface whose job is
sub-0.1 mm repeatability.

## Other consequences

- **Frame-and-panel construction, not monolithic shells.** A 250 mm limit plus a machine
  that is slow by 2026 standards means large one-piece bodies are both risky and a
  10+ hour commitment per iteration. A frame with bolt-on panels iterates one panel at a
  time.
- **Test coupons stay small.** Phase 1 port coupons are ~110 mm square, ~2–3 h each, so
  a design iteration is same-day rather than overnight.
- **PETG over PLA**, everywhere. PLA's glass transition is reachable by a vacuum motor's
  waste heat and by a sunlit window. ASA is better still but wants an enclosure the
  TAZ 6 doesn't have stock; revisit if the base is enclosed later.
- **Design for no supports.** Overhangs ≤ 45°; bridge rather than support; split parts at
  natural planes. Support removal on a 0.5 mm nozzle leaves scars on exactly the mating
  faces we care about.
- **Print orientation is a spec, not a slicer setting.** The latch collar and port flanges
  carry load in shear across layers. Orientation is recorded per part in its generator
  script and must not be changed casually.

## Alternatives considered

- **Fit a smaller nozzle (0.4 / 0.25 mm).** Not required — the steel-hardware rule removes
  the need for fine printed features entirely, and a 0.5 mm nozzle gives stronger, faster
  parts. Revisit only if a module needs genuinely fine detail.
- **Outsource precision parts to a print service or CNC.** Rejected for now: it breaks the
  same-day iteration loop that Phase 1 depends on. Reasonable later for a final chassis.

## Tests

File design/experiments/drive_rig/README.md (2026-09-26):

# Rolling drive rig

**2026-09-12 status: optional experiment.** The owner has asked to design around
documented, suitable components instead of qualifying uncertain owned parts.
See the [ground robot recommendation](../../../docs/GROUND_COMPONENT_RECOMMENDATION.md).
The rig, prints, metal-rod discussion and purchased controllers are retained;
the preparation steps below are not the main robot's next milestone.

This experiment uses **two owned BDUAV 2204-260KV motors, their directly attached
60 × 8 mm wheels, the owned ball caster, Pi 4 and 3S battery**. Add secured ballast
and measure travel time over a known distance. It is a ground-drive experiment;
EDF testing and whole-robot lift remain deferred.

The design is an **unpowered fit prototype**. CAD and recording tools exist;
closed-loop motor firmware and powered commissioning are still to do. Neither
the conflicting ML2206B sheet nor the controller's high-current rating supplies
a safe current setting for these motors. No powered drive-performance results exist.

**2026-09-12: the tape-wrap holder fits into the bore but wobbles and lacks
reach.** The owner proposes a metal rod in the now-reported 3.4 mm motor bore.
See [the metal-rod review](ENCODER_METAL_ROD.md) for fit, retention and magnetic
material considerations. No new print or rod cut length is released; keep the
existing encoder location while this is checked.

**Two B-G431B-ESC1 controllers are purchased and awaiting delivery**, as reported
2026-09-06. Follow [preparation before arrival](PREPARATION.md) for the immediate
print/measurement work and [USB-only diagnostics](firmware/README.md) for the
first controller checks. The diagnostic program does not drive the motors.

## Review and first print

- [Layout and interactive course calculator](output/drive_rig.html)
- [Complete hardware proposal and cost](HARDWARE.md), [editable BOM](hardware.csv)
- [Wheel-controller shopping criteria](../../../docs/DRIVE_CONTROLLER_REQUIREMENTS.md)
- [Controller alternatives and full-cost implications](../../../docs/DRIVE_CONTROLLER_OPTIONS.md)
  — retained for reference; the rig now uses the purchased ST controllers with
  the received external AS5600 encoders.
- [Assembly STEP](output/drive_rig_assembly.step), [FreeCAD assembly](output/drive_rig_assembly.FCStd)
- **One full 8.50 mm bracket now has a mounted motor that spins freely**, per
  the owner. The second bracket was last reported printing with support disabled;
  its completed quality and fit remain to check. **One caster riser is printed
  and mounted**, reported 2026-09-07; only one is needed.
  **HiLetgo board dimensions confirmed:** the received 23 × 23 mm board has
  16 × 16 mm hole centers, 4 mm holes and a centered chip, owner-confirmed.
  The [existing carrier](output/encoder_carrier_hiletgo_16mm.stl) and
  [mounting reference](ENCODER_MOUNT.md) record its inboard attachment. Hold
  duplicate encoder prints while retention is redesigned. The deck is printed;
  its geometry and the motor brackets are unchanged. See
  [preparation](PREPARATION.md) for the sequence and remaining physical checks.
- [Intended bracket shape in printing orientation](output/motor_bracket_8p50mm_preview.svg)
  — includes the reinforcing ribs and bolt-access cutouts; slicer-generated
  support/brim is not represented in the CAD model.

The deck is 220 × 240 mm. Wheel outside-to-outside width is 244 mm, track is
236 mm, axle height is 30 mm, and axle-to-caster contact spacing is 145 mm.
Ballast tray rim height is 110 mm. Reserve up to 150 mm total for secured
ballast/meter, Pi cooling and wiring. These are rig dimensions, not a new robot
module interface or a certified load rating.

## Printable parts

| Part | Quantity | Notes |
|---|---:|---|
| [Deck](output/deck.stl) | 1 | Flat underside on bed; ribs up; 220 × 240 × 12 mm |
| [Motor bracket, 8.50 mm pitch](output/motor_bracket_8p50mm.stl) | 2 | One motor mounted and spins freely; second bracket printing; generic motor_bracket.stl is also updated |
| [HiLetgo encoder carrier, 16 mm pitch](output/encoder_carrier_hiletgo_16mm.stl) | Reference | Existing inboard support; hold duplicate prints pending retention redesign |
| [Magnet stem fit gauges](output/magnet_stem_fit_gauges.stl) | Reference | 3.6 mm gauge fit, but full holder failed; no repeat gauge print requested |
| [Retired tape-wrap magnet carrier](output/magnet_carrier_tape_trial_2p8mm.stl) | History | Enters bore but wobbles and lacks reach; do not print/use |
| [Retired magnet carrier, 3.4 mm tip, neck +2.5 mm](output/magnet_carrier_4x2mm_stem_3p4mm_plus2p5mm.stl) | History | Failed retention and added drag; do not print/use this rigid-fit variant |
| [Caster riser](output/caster_riser.stl) | 1 | Printed and mounted, owner-reported 2026-09-07; rear support for the two-wheel/one-caster chassis |
| [Ballast tray](output/ballast_tray.stl) | 1 | Separate load shelf; protects the battery from ballast pressure |
| [Tray column](output/tray_column.stl) | 4 | Through-bolted, not self-tapped |
| [Electronics carrier](output/electronics_carrier.stl) | 2 | Generic insulated board support; verify actual board-edge clearance |

STLs are already oriented with their proposed bed face at Z=0. Use PETG for the
rig; a PLA coupon is fine. Start with 0.2 mm layers, 5 perimeters, 6 top/bottom
layers and 40% infill; use solid columns. These settings
are a starting point, not strength certification. The caster riser has internal
bridges in its side orientation: inspect the slicer's bridges and add local
support where needed.
Clean printed holes by hand and check that no screw rubs the rotating assembly.
The clip-like feature on the first bracket was identified by the owner as Cura
support. Support is disabled for their second bracket print; this is not yet a
completed support-free print result. Evaluate support separately for the riser
and other parts using the orientations and bridge notes above.

The [geometry report](output/geometry_report.json) checks closed meshes, single
solids, print extents and modeled assembly overlaps. It does not model every
wire, connector, screw head or board component. Solid CAD volume is **not** a
measured or slicer-estimated print mass. Weigh finished prints and hardware.

## Assembly

1. Print and check one updated 8.50 mm motor bracket, then the second identical
   part. Bolt the wheels to the rotating motor faces with
   their existing compatible M2 hardware. Wheel screw length depends on the
   actual material beneath the screw head; the full 8 mm tire width does not
   establish that stack. Keep screw tips clear of the motor internals.
2. Bolt each motor's stationary face to a printed bracket with four M2 × 6
   pan-head screws, nominally 2 mm engagement. Bolt each bracket below the deck
   with four M3 × 25 bolts through the stiffening ribs. Use washers and nuts;
   tighten without crushing the print.
3. Existing encoder attachment reference: the carrier attaches below each bracket with two M3 × 20 bolts through
   deck, bracket and carrier foot. Four screws through the PCB's corner holes
   and insulating spacers attach the stationary board to the carrier's upright
   plate. The sensor center faces the rotating magnet on the motor axis, with
   an air gap. The revised carrier has 3.4 mm bores on the owner's **16 × 16 mm**
   pattern. Use four **M3 × 12** screws/nuts, four **3 mm M3 spacers** and eight
   insulating washers per PCB. Check full nut engagement on the actual stack.
   The PCB's 4 mm holes allow adjustment: center before tightening, without
   bending the board. See [mounting reference](ENCODER_MOUNT.md). Hold further
   encoder support prints pending the replacement attachment.
4. Retire both the bare-stem and tape-wrap holders after the reported failures.
   Check the owner's [metal-rod approach](ENCODER_METAL_ROD.md) before relocating
   the encoder. Establish close fit in the rotating bore and usable straight
   support depth before specifying rod length, retention and magnet cap.
5. A replacement must retain rod and magnet, turn freely without wobble, and
   hold the sensor gap. Use hand-turn USB-only diagnostics to check field status
   and repeatable full-turn readings before powered commissioning. Current CAD
   illustrates the historical holder, not a qualified replacement assembly.
6. Fit the caster below its riser with two M3 × 14 bolts, then mount the riser to
   the deck with four M3 × 50 bolts. The current riser assumes the caster's
   chassis-mating face is 13 mm above the floor. Check all three contacts and a
   level deck. Shim a short caster down; revise the riser if it is too tall.
7. Mount the Pi on four 10 mm M2.5 spacers. Fit the two controller carriers on
   10 mm M3 spacers. Use thin insulating pads under component-free board edges
   and light ties through the carrier slots; no ties across components, and no
   conductive board surface against a fastener. Leave USB ports accessible.
8. Put a thin pad below the battery and secure it with two 15 mm straps through
   the deck. The measured 135 × 43 × 22 mm body fits the 140 × 50 × 30 mm
   reservation. Orient its long dimension across the deck, with both corner
   cable exits at the right end, and route leads clear of the tray columns.
   There is 20 mm to the tray underside before padding/straps. Mount the tray on the
   four 42 mm columns with M3 × 60 through bolts. Keep ballast centered near
   Y=100 mm; strap it independently of the battery. Strap the wattmeter on the
   tray and include it in the empty-rig mass. The measured 86 × 43 × 25 mm meter
   body fits the 162 × 64 mm clear interior (168 × 70 mm outside). Place its long
   dimension across the deck: centering leaves 38 mm at each cable end and
   10.5 mm on either side. Route the two power cables at each end gently over
   the rim; add insulating padding if low exits press against it. Body fit is
   checked in CAD; cable bend/plug/strap fit remains a physical assembly check.

The Pi and controllers sit toward the rear; route USB cables over the deck and
out of the tires. The rear strip holds the regulator and motor-stop switch with
insulated pads/ties. The rig uses the motor bearings directly, with no new shafts
or separate wheel bearings. That keeps the experiment simple; watch for wheel
play, rubbing and bearing heating as load increases.

## Electrical plan and software boundary

```mermaid
flowchart LR
  B[Owned 3S pack] --> F[5 A main fuse near pack]
  F --> W[Owned wattmeter SOURCE to LOAD]
  W --> R[5 V regulator]
  R --> P[Pi 4]
  W --> S[Latching motor-power stop]
  S --> FL[1 A initial branch fuse]
  S --> FR[1 A initial branch fuse]
  FL --> L[Left ST controller]
  FR --> D[Right ST controller]
  L --> LM[Left motor]
  D --> RM[Right motor]
  LE[Left AS5600] --> L
  RE[Right AS5600] --> D
  P <-->|USB serial| L
  P <-->|USB serial| D
```

Fuse values are initial wiring-protection choices, **not phase-current limits**.
Keep grounds common; keep both controller BEC outputs separate from the Pi's
regulator. A full 3S pack is 12.6 V: this is compatible with the proposed
controller supply interface, but does not mean applying 12.6 V continuously to a
motor winding is acceptable. Retain 3S for this experiment.

The [ST board](https://www.st.com/en/evaluation-tools/b-g431b-esc1.html) integrates
an STM32 MCU, three-phase power stage, current shunts and controller temperature
sensing. Use one per wheel, with its ST-LINK section attached. It needs **custom
sensored SimpleFOC firmware**, not the factory aircraft-control program. The
[SimpleFOC board examples](https://docs.simplefoc.com/library_examples) provide
the starting point. Its high-current protection protects the board; a much lower
motor current limit must be established for the actual motor.

Proposed encoder wiring is one AS5600 per controller, SDA to PB7 and SCL to PB8
at the sensor pads, using the board-specific pin mapping. Power the Adafruit
board from a verified 3.3 V controller rail with common ground so I2C pullups stay
at 3.3 V. Both sensors have address 0x36 but occupy **separate local buses**.
The [board wiring example](https://community.simplefoc.com/t/b-g431b-esc1-beginner-guide-i2c-guide/515)
and [current STM32 peripheral map](https://github.com/stm32duino/Arduino_Core_STM32/blob/main/variants/STM32G4xx/G431C%286-8-B%29U_G441CBU/PeripheralPins.c)
support this interface. Verify the actual controller revision against its
schematic before soldering; these are small pads, not plug-in servo headers.

Firmware must default to disabled, calibrate sensor/current conventions with
wheels raised, limit alignment voltage as well as running current, ramp speed,
and disable on stale commands, invalid encoder/field readings, undervoltage,
overcurrent or overtemperature. Both sides must stop when either faults. A local
command timeout of at most 250 ms and a bounded run duration are proposed; the
Pi must detect a lost motor link and stop its peer. The physical switch removes
motor bus power while the Pi keeps the log. Commission and verify these behaviors
before floor runs. The LiPo alarm and manual stop are additional bench controls,
not replacements for implemented motor shutdowns.

**No motor-control firmware is issued yet.** First collect unpowered resistance
between all three pairs of motor leads (A-B, B-C, C-A), with meter lead resistance
recorded, and check pair-to-case insulation. Then establish pole count, sensor
direction, current-sense calibration and conservative operating limits. Do not
borrow the disputed 1.3 A or 14-pole values. If resistance is too low for the
multimeter to resolve, record that rather than inventing a value.

## Measurement procedure

Use a level, clear wood/tile course away from stairs and dogs during these tests.
Check the caster for grit and floor marking first. The scale is for stationary
weighing; it is not part of the moving rig. Its **2 kg physical capacity still
includes anything tared**. Weigh parts or manageable subassemblies separately,
then sum without counting the same component twice. Include battery, screws,
straps, meter, wiring and ballast. Start empty; add 250 g increments only while
the previous step is satisfactory. The initial proposed **1.75 kg total cap** is
a cautious experiment boundary, not a proven safe working load. Stop sooner on
flex, wheel play, caster damage, current limiting or heating.

1. Mark a **2 m course**, plus clear stopping/run-out space. Fix a visible marker
   to the rig and film both course marks and the moving marker. Phone video with
   playback timestamps is the reference; wheel rotations alone miss wheel slip.
   For variable-frame-rate recordings, use timestamps rather than nominal FPS.
2. Start each standing-start run with the same marker at the start line. Time
   from its first movement until it reaches the finish line. This includes
   acceleration and must be labeled `standing_start`. A later `flying_start`
   run needs a separate approach distance; do not mix the two in an average.
3. After commissioning, try 0.15, 0.20 and 0.25 m/s commands, approximately
   48, 64 and 80 wheel RPM. **2 m in 10 s = 0.20 m/s average**; this is a target
   calculation, not a motor performance prediction. Initially run slower while
   checking steering and stopping behavior.
4. Repeat three times in each travel direction at each satisfactory mass/speed.
   Keep charge state, ballast location and surface comparable. Record incomplete
   runs and failed starts as failures, not as missing data.
5. Record bus voltage/current from the wattmeter display (manual observation or
   video); it has no established Pi data interface. Phase-current telemetry from
   each ST board will be separate. Do not infer winding current or motor-only
   power from total battery current, which includes Pi consumption.
6. Record start/end **stationary motor-case temperature** using the same probe
   spot, with motors stopped. Do not mistake controller NTC temperature for motor
   temperature. For the first exploratory runs, stop at 50 °C measured case or
   a 20 °C rise, whichever comes first; these are conservative test abort choices,
   not manufacturer thermal limits. Case sensing can lag winding temperature.
7. After successful short runs, evaluate repeated starts, reversals, turning in
   place and increasing-duration runs with the same mass. An empty rolling deck
   does not represent roller drag, a full dust bin, floor joints or a docking
   ramp. Final traction selection must include those loads on the cleaning bottom.

Use [record_run.py](record_run.py) on the Pi or development computer. It records
manual measurements and calculates speed; **it sends no motor commands**:

```sh
python3 design/experiments/drive_rig/record_run.py --help
# Replace placeholders with measured values; no example measurements are supplied.
python3 design/experiments/drive_rig/record_run.py \
  --run-id R001 --mass-g MEASURED_TOTAL --distance-m 2 \
  --elapsed-s MEASURED_SECONDS --target-m-s 0.15 --direction forward \
  --start-mode standing_start --surface wood --outcome completed
```

The tool accepts `--outcome failed` or `aborted` with no elapsed time, saving a
blank speed. Results append to [runs.csv](runs.csv). Use separate run IDs and
record firmware/profile revision in notes. Columns for bus readings, temperature
and start success remain blank until actually entered.

## Current questions and next milestone

The reported mounting dimensions are saved in the
[inventory](../../../config/owned_parts.json). The motor is measured at
28 × 13 mm; stationary holes are M2 with approximately 4 mm depth before an
obstruction, and the central bore rotates. Its nominal 3.4 mm diameter is corroborated by the owner-supplied listing;
rod fit and straight support length remain physical checks. The caster holes are 3.5 mm,
34 mm apart. The original 8 mm coupon failed fit; **the owner confirms the
8.50 mm coupon fits**. This establishes the selected printed pitch, without
claiming a new precision measurement of the metal motor. The
[preparation checklist](PREPARATION.md) preserves the remaining inventory question
and measurement blanks. The comparison STLs remain available as fit references.

One full bracket fit is confirmed with free motor rotation; the second is
last reported printing. One caster riser is now mounted; no second riser is
needed. The deck and one wheel/motor/encoder assembly are shown in the photo.
Next step: **verify bore fit/support for the [metal-rod proposal](ENCODER_METAL_ROD.md)**.
The tape carrier enters but wobbles and needs more reach. The wheel-face redesign
and its measurements can wait. No additional stem print is requested. The received
[HiLetgo AS5600](https://www.amazon.com/dp/B09KGWC1PT)
has an owner-reported 23 × 23 mm outline, 16 × 16 mm corner-hole pattern,
4 mm holes and centered chip. PCB thickness and component/header clearance
remain physical fit checks. See [ENCODER_MOUNT.md](ENCODER_MOUNT.md).
Battery and wattmeter body
dimensions fit the layout. AS5600s and an included 4 × 2 mm magnet are received;
ST controller receipt remains unreported. Report fit and the unpowered lead-pair
resistances; these let us finish wiring/firmware without guessing motor ratings.

Regenerate and verify:

```sh
XDG_CACHE_HOME=/tmp/tidybot-freecad-cache freecadcmd \
  -u /tmp/tidybot-rig-user.cfg -s /tmp/tidybot-rig-system.cfg \
  design/experiments/drive_rig/export_freecad.py
python3 design/experiments/drive_rig/generate.py
python3 -m unittest discover -s design/experiments/drive_rig -p 'test_*.py'
```

Current encoder geometry uses owner-measured HiLetgo board and magnet dimensions;
PCB thickness and chip projection remain allowances. The earlier Adafruit board
was only a design reference. See [ENCODER_MOUNT.md](ENCODER_MOUNT.md) for magnetic
requirements and physical fit checks.
Pi hole placement uses the [official Pi 4 drawing](https://datasheets.raspberrypi.com/rpi4/raspberry-pi-4-mechanical-drawing.pdf).

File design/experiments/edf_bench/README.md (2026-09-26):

# EDF bench draft, retaining cradle and fit gauge

Status: **bench build and purchases deferred; fan remains mounted in v2 cradle**.
The owner rejected the fixture cost and then deferred all propulsion work until
the other modules' dimensions and masses are established. Current work is
[core and ground modules](../../../docs/GROUND_MODULE_DESIGN.md).
The build instructions and hardware below are retained records.
The owner reports a successful local housing-gauge fit, followed by interference
between v1 and the central raised ring. V2 now fits that ring and body on the
cable-free side; the cable-exit side interferes. No
physical thrust, electrical or structural measurements have been taken. This experiment
supports the [EDF test brief](../../../docs/EDF_BENCH_PLAN.md); it does not change
the robot's reference lift design.

The draft uses a horizontal fan and a rigid, pivoting lever to press on the
owner's existing AWS SC-2kg scale. A 2:1 force ratio extends its usable thrust
range while keeping the fan's intake and exhaust away from the scale platform.
The owner has installed the fan with M3 nuts and bolts and can cut wood. The
[complete hardware proposal](HARDWARE_LIST.md) records the deferred pivot, stand,
wiring and measurement package. The [mounting-board step](MOUNTING_BOARD.md)
is part of that assembly. The stand
uses one cradle below the fan with cables upward; see the
[orientation diagram](output/mounting_orientation.svg).
V1 artifacts are retained for comparison.

## Review and print files

| Artifact | Purpose |
|---|---|
| [Deferred hardware proposal](HARDWARE_LIST.md), [CSV](hardware.csv), [budget](purchase_totals.md) | Historical package and cost; not a current purchase instruction |
| [Mounting-board build step](MOUNTING_BOARD.md) | Next: 120 × 140 × 18 mm board, drill pattern and M4 fastening |
| [V2 print and assembly instructions](CRADLE_V2.md) | Current prototype: confirmed body/ring fit, cable-up orientation and M3 hardware |
| [Cable orientation](output/mounting_orientation.svg) | One cradle below the fan, three cables above it; schematic routing |
| [V1 record and assembly notes](CRADLE_V1.md) | Failed physical fit; retained as a record |
| [V2 cradle STL](output/retaining_cradle_v2.stl) | Existing successful body/ring print: one part, 48 x 112 x 52.5 mm, base flat |
| [Cradle preview](output/retaining_cradle_v2_preview.svg), [assembly preview](output/retaining_mount_assembly_v2_preview.svg) | Review part and nominal fan/hardware fit |
| [Dimensioned side view](output/layout.svg) | Force direction, lever arms and packaging allowances |
| [Bench FreeCAD](output/bench_layout.FCStd), [STEP](output/bench_layout.step) | Includes cradle and mounting board; lever joints, stops and shielding remain to design |
| [Fit-gauge STL](output/unpowered_fit_gauge.stl) | Two loose half-rings for an unpowered fit trial |
| [Gauge FreeCAD](output/unpowered_fit_gauge.FCStd), [STEP](output/unpowered_fit_gauge.step) | Editable/exportable gauge geometry |
| [Calculations](output/calculations.md) | Static range and thrust targets; example preload is not a measurement |
| [Inputs](config.json) | Owner dimensions, source labels and proposed geometry |

## Measurement basis

| Item | Basis |
|---|---|
| EDF | Owner reports 66 mm duct length excluding the motor, 74 mm minimum body diameter, 75.5 mm lip diameter and 91 mm span across ears. Ear-hole spacing is approximately 82.5 mm; further ear details are recorded below. |
| Scale | Owner identifies AWS SC-2kg and measures a 100 x 100 mm platform. AWS specifies 2,000 g capacity and 0.1 g readability; readability is not accuracy under motor vibration. |
| Meter | Owner's KREATORDIRECT listing says 50 A continuous and 0-60 V. Photo says 150 A, while listing range says 0-200 A. Those inconsistent range labels do not increase the adopted continuous limit. |
| Wiring | Meter photo shows bare/tinned SOURCE and LOAD leads; a visible wire is marked 12 AWG. Actual connector, joint and complete harness capability remain to verify. |

Scale references: [AWS product page](https://awscales.com/sc-2kg-precision-digital-pocket-scale-2kg-x-0-1g/)
and [SC-Series manual](https://awscales.com/content/scales/SC-Series/SC-Series_manual.pdf).
Use the owner's measured platform dimensions where catalog dimensions differ.
The meter rating comes from the listing text supplied by the owner, not a test
of this unit. Original photos remain outside this repository.

## Completed physical check: housing fit gauge

**Owner result:** "ring gauge fits around the housing without force." This is
recorded in `physical_checks.housing_fit_gauge` in [config.json](config.json).
It supports retaining the 74.4 mm bore for the plain body region. The full cradle
subsequently failed to clear the raised central ring. The gauge instructions below
are retained for reproduction; its success did not validate the longer saddle.

The STL contains two separate semicircular pieces with a **74.4 mm bore**, 4 mm
radial wall and 6 mm axial height. The extra 0.4 mm is a trial diametral clearance,
not a claim about printer accuracy or the eventual mount fit. Combined print
footprint is approximately 172.8 x 41.2 mm, within the TAZ 6 bed.

Print flat at 100% scale, in millimetres. PLA or PETG, 0.25 mm layers and 3-4
perimeters are reasonable starting choices for this unpowered gauge; no supports
are needed. With the battery disconnected, bring the two halves together around
the measured 74 mm section. They should meet at their flat ends without forcing
or squeezing the duct. Report whether they meet, leave a gap, or have noticeable
radial play, and whether a full 6 mm-wide band of housing is available there.

These pieces have no fasteners or positive axial retention. **Do not use them to
hold a running fan.** Do not remove the bellmouth or disturb the balanced rotor
for this check. Remove loose hair around the fan with power disconnected before
any subsequent powered work.

### Mount measurements

| Owner measurement | Value (mm) | Interpretation |
|---|---:|---|
| Duct length | 66 | Along airflow, excluding protruding motor |
| Minimum body outside diameter | 74 | Gauge bore remains 74.4 mm |
| Inlet-lip outside diameter | 75.5 | Not the rotor diameter |
| Outside span across mounting ears | 91 | Overall width, not a circular body diameter |
| Opposite ear-hole center spacing | Approximately 82.5 | Owner's best estimate; not an exact hole-pattern tolerance |
| Hole diameter | 4 | Owner confirmed the opening diameter |
| Ear thickness along mounting screw | 3 | Owner confirmed this is the material the screw passes through |
| Ear width | 8 | Hole reported centered, 4 mm from each width edge |
| Ear height along the duct | 20 | Hole centered height-wise |
| Intake-side end of ear, measured from motor-side duct end | 39 | Motor excluded from reference |
| Hole center from motor-side duct end | 29 | Derived: 39 - 20/2 |
| Hole center from intake face | 37 | Derived: 66 - 29 |
| Ear ends from intake face | 27 and 47 | Derived from the 20 mm ear height |
| Central ring OD and axial width | 75.5 and 1.5 | Owner measured |
| Central ring center from intake face | 37 | Owner confirms alignment with the ear-hole centers |
| Central ring edges from intake face | 36.25 and 37.75 | Derived from its center and width |

The CAD now includes nominal rectangular **20 x 8 x 3 mm ears with 4 mm holes**.
Hole centers lie 37 mm from the intake face and approximately 41.25 mm either
side of the fan axis. In the bench layout, the ears are oriented sideways and
their screw axes are vertical. Corner shapes and root fillets are not measured;
these ear solids represent the existing fan, not replacement parts to print.

The 8 mm nominal ear width and approximately 82.5 mm center spacing imply a
90.5 mm outside span, versus the owner's 91 mm overall measurement. Keep 91 mm
for clearance and treat the 0.5 mm difference as measurement uncertainty rather
than forcing all dimensions to be exact. The retaining mount should accommodate
the approximate spacing and be checked on the actual fan before powered use.

A separate 100 x 95 x 95 mm package allowance remains while motor protrusion is
unmeasured; its inlet face aligns with the duct's inlet face. The 66 mm measurement
is the duct length, not the complete assembly length. The
[updated dimension sketch](output/mount_measurement.svg) shows the resolved
37 mm intake-side and 29 mm motor-side references. The earlier 3.25 mm offset
derived from radial lip overhang is not an axial mounting dimension.

The gauge fit is confirmed, but the v1 cradle trial failed at the central ring.
The [v2 groove](CRADLE_V2.md) is 76.1 mm diameter × 2.5 mm wide, centered at
37 mm from the intake. The fan model now includes the measured 75.5 × 1.5 mm
ring. The owner confirms v2 fits on the cable-free side, including the ring.
Use that side underneath with the three cables upward. The exit area is reported
as 6 × 11 mm, between the ears and on the motor side of the ring; exact dimension
axes/protrusion remain unconfirmed. V2 uses 6 mm OD M3 washers; hardware fit
has now been reported with M3 nuts and bolts. Final cable routing and retention
under load remain to check.

## Force measurement geometry

All dimensions below are proposed, not owner measurements. Bench coordinates are
x toward the exhaust, y across the bench, z up. Heights use the base's top face.

| Feature | Proposed geometry |
|---|---:|
| Fixed base allowance | 600 x 320 x 18 mm |
| Horizontal pivot axis | x = 330 mm, z = 180 mm |
| Fan thrust line | 120 mm above pivot; exhaust to the right |
| Scale contact | 240 mm left of pivot, centered on its platform |
| Selected pivot shaft | 8 mm round diameter, 200 mm stock length; bearings initially at y = +/-65 mm |
| Measured fan duct envelope | 66 mm long, 75.5 mm lip diameter, 91 mm span across ears; motor excluded |
| Full fan package allowance | 100 x 95 x 95 mm; motor protrusion remains unmeasured, ear corners/root fillets simplified |
| Cradle and board | 48 x 112 x 52.5 mm cradle on a 120 x 140 x 18 mm board; fan axis 54 mm above board top |
| Scale case allowance | 132 x 110 x 21 mm; check display and cover clearance |

Thrust acts left above the pivot. The left lever arm therefore presses down on the
scale. The pivot carries the remaining static load and the horizontal reaction.
With the lever level and its actual distances measured:

```text
thrust_gf = (gross_scale_g - baseline_scale_g) * L / h
L = 240 mm, h = 120 mm -> thrust_gf = 2 * change_in_scale_g
```

| Reference thrust | Increment on scale |
|---|---:|
| 1,000 gf | 500 g |
| 1,055.6 gf, hover per fan at the current four-fan robot mass | 527.8 g |
| 1,810 gf, DD seller's unverified maximum claim | 905 g |
| 2,111.2 gf, current per-fan available-thrust target | 1,055.6 g |

Record the actual gross baseline before taring; taring does not restore load
capacity. The proposed working stop is **1,800 g gross**, allowing 200 g below the
scale's rated capacity. With an *example* 200 g baseline, that corresponds to
3,200 gf thrust. Actual usable range depends on the measured baseline and dynamic
loads. The 2,111.2 gf target fits below that working stop only if the baseline is
below 744.4 g, with further margin needed for fluctuations. Printed display steps
of 0.1 g become 0.2 gf at this ratio; this is not an accuracy specification.

Use a rounded, adjustable contact at the center of the platform. Avoid side load
or contact with the fixed scale case. Arrange flexible motor cables so they do
not restrain lever motion; the ESC and battery remain on the fixed side. Moving
parts must clear the fixed structure except at the pivot and scale contact.

Before power, apply known masses at the marked calibration point 120 mm left of
the pivot: 1,000 g there should add 500 g to the scale. Check several loads while
increasing and decreasing, dwell at each, then remove them and check baseline
return. Repeat with the final cables installed. This checks the moment ratio,
friction and scale behavior; it does not fully validate horizontal-force coupling
or readings during fan vibration. A later known horizontal load along the fan
axis should also verify the assembled thrust load path.

Reject readings if auto-zero, hold/filtering, power-off, bearing friction, drift
or cable forces prevent repeatable load changes. If those cannot be controlled,
use a suitable load cell/thrust instrument. The lever avoids an immediate scale
replacement; it does not guarantee this pocket scale will perform adequately.

## Construction and electrical work remaining

The stand CAD combines a packaging study with a printable cradle prototype;
it is not a proof of strength or a complete fixture cut list. The intended
fabrication approach uses drilled timber/metal sections, bolts and purchased
bearings/shaft; printed adapters locate the housing after a fit check. No lathe
or mill is assumed. Purchased parts are selected in the
[complete hardware list](HARDWARE_LIST.md); installation checks remain:

| Item | Installation / verification still needed |
|---|---|
| Selected goBILDA 8 mm pillow blocks, 200 mm shaft and round clamping hubs | Detail lever joints and confirm delivered dimensions, friction and retention; 24 mm bearing axis height |
| Fixed supports, braced moving lever, base clamps and bolts | Stiffness, load capacity, clearance and fastening details |
| Fan mount | Fan installed in v2 with M3 nuts and bolts. Next attach the cradle to the moving board; load validation remains |
| Adjustable contact and mechanical stops | Central contact, travel limit and overload protection without shunting normal measured force |
| Access barrier and shielding | Independent support outside the flow path; duct and printed gauge are not containment |
| Manual servo tester | Recommended TST-20 and ESC BEC wiring are in the test brief |
| Selected harness, MIDI fuse and Albright ED125-1 | Complete circuit assembly, accessible shutdown and insulated connections; see purchasing list |

Connect the main power path as battery -> suitable protection/interrupter -> meter
**SOURCE** -> meter **LOAD** -> ESC. The photo's exposed wire ends need properly
soldered, insulated mating connections. Match the battery's XT60 contact type at
SOURCE and the actual ESC input at LOAD (product page lists XT90); check polarity
with the multimeter before connecting the battery. Connector names alone do not
specify mating orientation. Confirm the EDF's phase bullets against the ESC's
listed 4 mm bullets. Do not use an ordinary multimeter's current input for EDF
current.

Leave the meter's thin auxiliary lead unused and insulated for the 3S experiment;
its pinout is unverified and auxiliary power is unnecessary at this pack voltage.
Despite the listing's wording about preventing current damage, treat this device
as a meter: **it does not establish current limiting or automatic shutdown**.

Proposed limits for the existing meter are a **20 A initial ceiling**, with a
later **40 A operator stop** if the first checks support it, below the supplied
50 A continuous rating. These are experiment choices, not hardware validation or
automatic protection. Component temperatures, individual-cell voltage limits, run
duration, circuit protection and interruption capability still need to be fixed
before the powered protocol is released. No full-throttle or 4S run is specified
by this layout. A future higher-current run needs a separately rated power path.

## Regeneration and verification

From the repository root:

```sh
python3 design/experiments/edf_bench/generate.py
freecadcmd design/experiments/edf_bench/export_freecad.py
freecadcmd design/experiments/edf_bench/verify_mount.py
```

Set `TIDYBOT_PROJECT_ROOT` if invoking FreeCAD from another directory. Inputs and
scripts govern the retained outputs; do not hand-edit generated files. The
exporter checks nonempty valid CAD shapes and a closed STL mesh. These software
checks establish file integrity, not physical strength, fit or measurement quality.

The [current verification report](output/mount_verification.json) records v2
geometry checks, the reported cable-free-side body/ring fit and subsequent M3
installation. The moving board and complete fixture remain to assemble. The v1 failure remains
in config and its historical print record. The [v2 instructions](CRADLE_V2.md)
describe the measured-ring checks and separate synthetic regression.
No thrust readings have been entered in the recording sheet.

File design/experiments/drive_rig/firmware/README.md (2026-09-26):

# USB-only ST controller diagnostic

This program checks a B-G431B-ESC1's USB serial link and an optional AS5600 sensor.
It has **no motor-drive commands, PWM generation, FOC, alignment or calibration**.
Use it with the **battery and all motor phase wires disconnected**. Keep the
ST-LINK daughterboard attached. USB supplies the MCU for these checks, as
described in [ST UM2516, sections 5.3 and 6.1](https://www.st.com/content/ccc/resource/technical/document/user_manual/group1/86/3f/45/e0/12/18/47/85/DM00564746/files/DM00564746.pdf/jcr%3Acontent/translations/en.D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).

## Build on the development computer

From the repository root (the local environment is already installed in this
workspace; the first two commands are for another computer):

```sh
python3 -m venv .venv-drive-rig
.venv-drive-rig/bin/python -m pip install platformio==6.1.18
export PLATFORMIO_CORE_DIR=/tmp/tidybot-platformio
.venv-drive-rig/bin/pio run -d design/experiments/drive_rig/firmware
```

The platform is pinned to `ststm32@20.0.0`; the verified resolved Arduino package
is `framework-arduinoststm32@4.30000.0` (core 3.0.0), with GCC 12.3.1. No motor or
third-party sensor library is required. The framework supplies Wire and serial.
See [PlatformIO's board configuration](https://docs.platformio.org/en/latest/boards/ststm32/disco_b_g431b_esc1.html).

**Build checked on 2026-09-06:** 31,100 bytes flash, 1,780 bytes static RAM.
This includes neither a hardware run nor measured stack/heap high-water usage.
The boards have not arrived. USB operation, field readings and electrical
outputs remain to be checked on the actual hardware. No upload was performed.

## First USB check after delivery

1. Disconnect battery, motor leads and external circuits. Place one intact board
   on a nonconductive surface and connect its ST-LINK Micro-B port by a data cable.
   Flash only one ST board at a time so the programming target is unambiguous.
2. Run the following from the repository root, using the same environment as
   the build. Upload replaces the application on the motor-control MCU; it does
   not intentionally modify the attached ST-LINK firmware.

```sh
export PLATFORMIO_CORE_DIR=/tmp/tidybot-platformio
.venv-drive-rig/bin/pio run -d design/experiments/drive_rig/firmware -t upload
.venv-drive-rig/bin/pio device list
.venv-drive-rig/bin/pio device monitor -p /dev/ttyACM0 -b 115200
```

Choose the enumerated port rather than assuming `/dev/ttyACM0` belongs to this
board. On Linux, USB programming and serial access may need the appropriate
[PlatformIO udev rules and user permissions](https://docs.platformio.org/en/latest/core/installation/udev-rules.html).
Close the monitor with Ctrl-C. A later monitor command can add `--filter log2file`
to retain observations; keep such logs separate from measured driving runs.

3. Expect newline-delimited JSON containing firmware `tidybot-usb-diag-0.1`, a
   24-hex-character `board_id`, increasing `uptime_ms`, and `motor_drive:false`.
   Without a sensor, expect `i2c_ok:false`, `field_ok:false`, and null angle/field
   flags. These are expected states, not sample results already measured.
4. Label this board L or R and save its ID. Repeat with the other board. Later
   both can connect to the Pi, but `/dev/ttyACM` numbers can change with enumeration;
   associate sides using the observed board IDs/USB identities.
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

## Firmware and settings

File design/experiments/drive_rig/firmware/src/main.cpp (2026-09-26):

// USB-only B-G431B-ESC1 diagnostic. Disconnect battery AND motor leads.
// This program has no motor-drive commands, PWM, alignment or FOC code.
#include <Arduino.h>
#include <Wire.h>

#if !defined(ARDUINO_B_G431B_ESC1) || !defined(A_PHASE_UL)
#error "Build only for disco_b_g431b_esc1 with its board-specific pin map."
#endif

namespace {
constexpr uint32_t gateInputs[] = {
    A_PHASE_UH, A_PHASE_UL, A_PHASE_VH,
    A_PHASE_VL, A_PHASE_WH, A_PHASE_WL,
};
constexpr uint8_t sensorAddress = 0x36;
constexpr uint8_t statusRegister = 0x0B;
constexpr uint8_t rawAngleRegister = 0x0C;
constexpr uint32_t reportPeriodMs = 100;
uint32_t lastReportMs = 0;
char boardId[25] = {};

void holdGateInputsLow() {
  for (const auto pin : gateInputs) {
    digitalWrite(pin, LOW);
  }
}

bool readRegisters(uint8_t firstRegister, uint8_t *bytes, size_t count) {
  Wire.beginTransmission(sensorAddress);
  Wire.write(firstRegister); // Register pointer only; no sensor settings written.
  if (Wire.endTransmission(false) != 0) {
    return false;
  }
  if (Wire.requestFrom(sensorAddress, count, true) != count) {
    while (Wire.available()) {
      Wire.read();
    }
    return false;
  }
  for (size_t i = 0; i < count; ++i) {
    bytes[i] = static_cast<uint8_t>(Wire.read());
  }
  return true;
}

void report() {
  uint8_t status = 0;
  uint8_t angleBytes[2] = {};
  const bool i2cOk = readRegisters(statusRegister, &status, 1) &&
                    readRegisters(rawAngleRegister, angleBytes, 2);
  const bool detected = (status & 0x20) != 0;
  const bool weak = (status & 0x10) != 0;
  const bool strong = (status & 0x08) != 0;
  const bool fieldOk = i2cOk && detected && !weak && !strong;
  const uint16_t raw = ((uint16_t(angleBytes[0]) << 8) | angleBytes[1]) & 0x0FFF;

  Serial.print("{\"firmware\":\"tidybot-usb-diag-0.1\",\"board_id\":\"");
  Serial.print(boardId);
  Serial.print("\",\"uptime_ms\":");
  Serial.print(millis());
  Serial.print(",\"motor_drive\":false,\"i2c_ok\":");
  Serial.print(i2cOk ? "true" : "false");
  Serial.print(",\"field_ok\":");
  Serial.print(fieldOk ? "true" : "false");
  Serial.print(",\"magnet_detected\":");
  Serial.print(i2cOk ? (detected ? "true" : "false") : "null");
  Serial.print(",\"field_weak\":");
  Serial.print(i2cOk ? (weak ? "true" : "false") : "null");
  Serial.print(",\"field_strong\":");
  Serial.print(i2cOk ? (strong ? "true" : "false") : "null");
  Serial.print(",\"raw_angle\":");
  if (i2cOk) {
    Serial.print(raw);
  } else {
    Serial.print("null");
  }
  Serial.println("}");
}
} // namespace

void setup() {
  // Both L6387 inputs low commands each half-bridge off (L6387E datasheet).
  // USB-only operation and disconnected motor leads are still required:
  // this application cannot control reset, bootloader or pre-flash firmware.
  holdGateInputsLow();
  for (const auto pin : gateInputs) {
    pinMode(pin, OUTPUT);
  }
  holdGateInputsLow();
  snprintf(boardId, sizeof(boardId), "%08lX%08lX%08lX",
           static_cast<unsigned long>(HAL_GetUIDw0()),
           static_cast<unsigned long>(HAL_GetUIDw1()),
           static_cast<unsigned long>(HAL_GetUIDw2()));
  Serial.begin(115200); // USART2 PB3/PB4 through the attached ST-LINK VCP.
  Wire.setSDA(PB7);
  Wire.setSCL(PB8);
  Wire.begin();
  Wire.setClock(100000);
}

void loop() {
  holdGateInputsLow();
  const uint32_t now = millis();
  if (uint32_t(now - lastReportMs) >= reportPeriodMs) {
    lastReportMs = now;
    report();
  }
  // Incoming serial bytes are deliberately not interpreted as commands.
  // Wire/USB delays may delay reports; this is not a motion-control watchdog.
}

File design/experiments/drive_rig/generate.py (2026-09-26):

"""Generate offline drawings, course calculator and BOM summary from rig inputs."""
import csv
import html
import json
from decimal import Decimal
from pathlib import Path

HERE = Path(__file__).resolve().parent
OUT = HERE / 'output'
OUT.mkdir(exist_ok=True)
C = json.loads((HERE / 'config.json').read_text())
motor_pitch = C['motor']['stationary_hole_pattern_mm']
motor_pitch_label = ' × '.join(f'{p:.2f}' for p in motor_pitch) + ' mm'
bracket_file = 'motor_bracket_' + f'{motor_pitch[0]:.2f}'.replace('.', 'p') + 'mm.stl'
bracket_fit_count = C['motor']['mount_fit']['bracket_physical_fit_count']
with (HERE / 'hardware.csv').open(newline='') as f:
    BOM = list(csv.DictReader(f))
total = sum(Decimal(r['unit_usd'])*int(r['quantity']) for r in BOM)
quoted = sum(Decimal(r['unit_usd'])*int(r['quantity']) for r in BOM if 'manufacturer' in r['price_basis'])
remaining = sum(Decimal(r['unit_usd'])*int(r['quantity']) for r in BOM
                if r['status'] not in ('purchased awaiting delivery', 'received'))
table = '\n'.join(f"| {r['quantity']} | {r['item']} | ${Decimal(r['unit_usd'])*int(r['quantity']):.2f} | {r['status']} | {r['price_basis']} |" for r in BOM if Decimal(r['unit_usd']))
(HERE / 'HARDWARE.md').write_text(f'''# Rolling rig hardware and purchase status

**Received: two HiLetgo AS5600 boards**, per owner report on 2026-09-07.
An included 4 × 2 mm magnet is also received; total magnet count is unconfirmed.
Two B-G431B-ESC1 boards remain ordered with receipt unreported.
The earlier ST estimate was later in the week; actual paid prices are unknown.
**Remaining planning allowance: ${remaining:.2f} before shipping/tax**, before
deducting any additional supplies already owned or ordered. Received encoders, bundled magnets and purchased controllers
are excluded from this remaining allowance.

The current complete-path planning reference total is **${total:.2f} before shipping/tax**.
It includes all listed
purchase allowances and consumable/media allowances, assuming reuse of the
owned motors, wheels, caster, Pi, battery, wattmeter, scale and tools. It is
not a purchase receipt. Only **${quoted:.2f}** uses observed manufacturer prices;
the remaining **${total-quoted:.2f}** uses explicitly labeled allowances. Regional
availability, taxes, minimum packs and shipping can change the total. A full
filament spool, if needed, costs more than the filament consumption allowance.
There is no dedicated force stand or precision scale purchase.

| Qty | Item | Reference/allowance USD | Status | Price basis |
|---:|---|---:|---|---|
{table}

The [CSV](hardware.csv) includes source links, quantities, owned items, wiring
notes and every allowance. Controller selection is the purchased ST path,
not interchangeable with the owned aircraft ESC or a brushed H-bridge.

Selected controllers and proposed supporting electronics:

- [ST B-G431B-ESC1](https://estore.st.com/en/products/evaluation-tools/product-evaluation-tools/mcu-mpu-eval-tools/stm32-mcu-mpu-eval-tools/stm32-discovery-kits/b-g431b-esc1.html):
  two purchased; $38.98 each is the earlier observed reference, not the receipt.
  Includes MCU, driver, current sensing and
  ST-LINK programmer, so no separate ESP32, PWM board, current-sense shield or
  servo tester is required. Small-pad soldering and custom firmware are required.
- [HiLetgo AS5600 module](https://www.amazon.com/dp/B09KGWC1PT): two received;
  owner reports 23 × 23 mm, 16 × 16 mm hole centers, 4 mm holes and centered chip.
  Hold further encoder support prints pending the retention redesign. The $5.95 each retained in the planning
  table is the historical Adafruit reference, not the HiLetgo purchase price.
- **Included HiLetgo magnet, 4 × 2 mm**, owner-measured: no separate magnet
  purchase allowance. The rig needs two; total received count is unconfirmed.
  Both the rigid-fit holder and tape trial are retired; the tape version enters
  but wobbles and lacks reach. Evaluate the owner's [metal-rod proposal](ENCODER_METAL_ROD.md)
  before moving the encoder. No rod diameter tolerance, cut length, retention
  method or cap geometry is released. Existing magnets/boards are candidates
  for reuse; magnetic field and mechanical alignment must be verified.
- [Pololu D24V50F5](https://www.pololu.com/product/2851): one; $35 allowance,
  not an observed price. It supplies the Pi; the motor controllers use the fused
  3S bus. Check regulator temperature and Pi rail voltage under actual USB load.

Fastener quantities for the modeled assembly (buy an assortment with spares):

| Location | Fasteners/spacers |
|---|---|
| Stationary motor faces | 8 × M2 × 6 pan head; nominal 2 mm engagement through 4 mm plate |
| Wheels | Existing M2 fasteners if suitable; otherwise select from assortment after measuring actual hub stack and clearance |
| Motor feet | 8 × M3 × 25, washers and nuts |
| Encoder carrier feet | 4 × M3 × 20, washers and nuts |
| Sensor boards | 8 × M3 × 12 screws/nuts (nylon preferred), 8 × 3 mm M3 insulating spacers, 16 insulating M3 washers; verify component clearance/full nut engagement; adjust spacers for actual sensor gap |
| Caster to riser | 2 × M3 × 14, washers and nuts; inspect ball/housing clearance |
| Caster riser to deck | 4 × M3 × 50 through bolts, washers and nuts |
| Ballast shelf | 4 × M3 × 60 through bolts, washers and nuts; 4 printed 42 mm columns |
| Pi | 4 × 10 mm M2.5 female spacers; 4 × 8 mm and 4 × 6 mm screws; verify spacer threads before tightening |
| Two controller carriers | 8 × 10 mm M3 female spacers; 16 × M3 × 8 screws with washers; board retention by edge pads/light ties |

No threaded inserts, machined hubs, new shafts or separate wheel bearings are
required. The small contact thermometer is a $20 allowance, not a selected SKU.
Regulator/switch/connector physical fit and actual stock still need checking
when choosing vendors. AS5600s and an included magnet are received; ST controllers are ordered.

See [ENCODER_MOUNT.md](ENCODER_MOUNT.md) for the first HiLetgo carrier fit and
per-board hardware. M3 replaces the earlier M2.5 sensor mounting hardware.

See [preparation before arrival](PREPARATION.md) for the remaining order checklist,
fit prints and measurement blanks. See the [assembly and test instructions](README.md) for wire routing, initial
fuse choices, low-current commissioning and the remaining firmware work.
''')

def esc(s): return html.escape(str(s))
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

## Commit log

2026-09-05 Phase 0: project foundation and TB-Port v0.1 (superseded)
    Establishes the parametric CAD pipeline, the decision record, and the
    budgets that everything downstream depends on.
    Kept:
    - ADR 0001-0005: locomotion in the base, 24 V bus, CAN, two ports,
    TAZ 6 design rules (steel for precision, never printed plastic)
    - Headless FreeCAD build: one `PORT` dict is the single source of
    truth; `make check` is a real regression test, not a formality
    - Mass, power, envelope and cost budgets
    Superseded: the TB-Port v0.1 geometry itself (boss-and-bore) is retained
    as a baseline, not as a design to build. It carries three known bugs,
    each caught by inspection rather than by the checks:
    1.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
2026-09-05 TB-Port 0.2.0: three tapered posts with cross pins
    Replaces the boss-and-bore coupling. Rationale in ADR 0006; the structural
    consequences of flying as a 3-stack in ADR 0007.
    Geometry:
    - 3 identical tapered steel posts at 0/120/235 deg on a Ø100 circle
    - Ø5 cross pins in double shear, driven by a cam plate inside the base
    - Central connector cone leads the posts by 4 mm and carries all 8 contacts
    - Lip seals, perimeter gasket, and a drain from every socket to the side wall
    Why this shape:
    - Three posts is exactly determinate (6 constraints, 6 DOF). Four is
    over-constrained and rocks or jams in printed plastic.
    - The taper rides on the post, so capture costs zero receptacl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
2026-09-05 Posts are steel, pressed into bores -- not printed
    The BOM called for Ø10 steel dowels while the CAD fused the posts into the
    printed plate. The model had nowhere to put the hardware it asked you to buy.
    This mattered beyond tidiness. The locking pin bears INSIDE the post's
    cross-hole; in printed PETG that hole crushes long before the 20x bearing
    margin, which assumed the base socket wall was the only plastic in the load
    path. It also contradicted ADR 0005 -- printed plastic is bulk and rough
    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
2026-09-05 Retention: circumferential groove + one rotating lock plate
    Replaces the cross-pin. Prompted by asking whether the posts could be
    bought rather than made, which exposed that the taper was never the hard
    part -- the cross-hole was.
    A cross-hole through a round bar needs a V-block and a centre punch or the
    drill walks off the crown. In hardened stock it wants carbide or EDM, which
    ruled out buying ready-made ground locating pins -- the one off-the-shelf
    route that solves the taper. A groove is a single lathe op, or a round file
    held against the rod while it spins in a drill press. Both features on the
    post can now be cut that way.
    Mechanically equivalent: still double shear, and the numbers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
2026-09-05 Materials: stainless, grade 303 -- not mild steel
    I specified mild steel for machinability and never checked it against the
    environment. The posts sit exposed whenever a module is off, on a machine
    whose job includes wet floors.
    Rust is not cosmetic here. It SWELLS: a rusted Ø10 post binds in a Ø10.2
    socket, which is the one clearance the whole joint depends on. It also sheds
    abrasive particles into a joint rated for 500 mates, and stains whatever the
    module touches.
    Strength is a non-issue. Austenitic stainless yields around 205 MPa against
    mild steel's 250, so margins fall from 74x/151x to 61x/123x.
    Grade matters for a different reason:
    303 free-machining, sulphur added. Buy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
2026-09-05 Bond the posts; guard that the contacts can actually close
    Two things surfaced from asking whether conductivity matters now that the
    posts carry no signal.
    1. The posts are still metal bridging the base to every module, and floating
    metal on a machine that generates static is a bad default. A vacuum builds
    serious charge, and a floating assembly will accumulate it and dump it
    into the connector at the worst moment.
    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
